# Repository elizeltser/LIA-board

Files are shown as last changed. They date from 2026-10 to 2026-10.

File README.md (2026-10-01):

# GMOS LIA Readout Board
 
KiCad project implementing the PCB for the GMOS readout based on the lock-in amplifier (LIA) approach. The board replaces the bench setup (SR860 lock-in + SR560 pre-amplifier + lab supplies) used for the 3T differential measurement of the GMOS active/blind transistor pair.
 
> **Legend:** `TODO` marks design work still to be done. `ASSUMPTION` marks a value used for sizing that must be confirmed.
 
---
 
## Table of Contents
 
1. [Schematic Overview](#1-schematic-overview)
2. [Measurement Principle & Design Considerations](#2-measurement-principle--design-considerations)
3. [DC (Power) Section](#3-dc-power-section)
4. [Analog Section](#4-analog-section)
5. [Digital Section](#5-digital-section)
6. [Power Budget](#6-power-budget)
7. [Simulation](#7-simulation)
8. [Lab Tests](#8-lab-tests)
9. [Open Items](#9-open-items)
10. [References](#10-references)
---
 
## 1. Schematic Overview
 
The schematic is split into the following sheets:
 
| Sheet | Content |
|---|---|
| 1 | Connectors, GMOS socket |
| 2 | Analog readout section |
| 3 | Digital readout section |
| 4 | DC (power) section |
 
---
 
## 2. Measurement Principle & Design Considerations
 
### 2.1 Device and Sensing Mechanism
 
The GMOS is a micromachined CMOS-SOI pixel containing a transistor (29 nMOS devices in parallel, W = 204 µm, L = 4.15 µm) and an integrated heating resistor. Each package provides two usable differential channels, each composed of an **active** pixel (exposed, with catalytic layer) and a **blind** pixel (inert reference).
 
Gas combustion on the catalytic layer releases heat, raising the active pixel temperature by ΔT. This shifts the threshold voltage and subthreshold drain current of the active transistor relative to the blind one, and the difference appears as a differential signal between the two drain nodes. Because the blind pixel sees the same heater, ambient and supply conditions, common-mode drifts are rejected by the differential readout.
 
### 2.2 3T Readout Method
 
Each transistor is operated in a three-terminal configuration:
 
- **Gate:** DC bias plus a small sine excitation at the lock-in reference frequency.
- **Drain:** connected through a series load resistor R_D (≈ 330 kΩ) to a programmable supply.
- **Heater:** DC voltage, trimmed per pixel to equalize the drain currents of the active/blind pair.
The gate modulation δV_GS produces a drain-current modulation g_m·δV_GS, which R_D converts to a voltage. The lock-in output is therefore proportional to the differential transconductance:
 
$$
\Delta v_{d} = -(g_{m,A} - g_{m,B})\cdot \delta V_{GS}\cdot R_D
$$
 
The minus sign reflects the inverting common-source stage. The phase θ carries information on reactive elements in the signal path and is used for calibration.
 
### 2.3 Bench Setup → Board Block Mapping
 
| Bench instrument / setting | Board block | Notes |
|---|---|---|
| SR860 reference out, 990 mV offset | Gate DC DAC + scaling op-amp + summing amp | Board range 0.97–1.2 V |
| SR860 reference out, 5 mVrms (≈ 14.1 mVpp) | Quadrature oscillator (518 Hz) + attenuating summing amp | Board: 5 mVpp |
| Lab supply on drain resistors | Drain DACs + scaling op-amps + R_D | Board range 2.7–3.5 V |
| Lab supply on heaters (2.7–2.9 V) | Heater DACs + driver op-amps | Board range 2.5–4.0 V |
| SR560: differential input, gain 20 V/V, BPF 300 Hz–1 kHz (6 dB/oct) | INA (G = 10, DC-coupled) → SK HPF → SK LPF → ×4 | Board: 40 V/V, 377–711 Hz (12 dB/oct) |
| SR860 demodulator (X, Y, R, θ) | AD630 pair + post-LPF (τ = 500 ms) + 24-bit ADC; R, θ computed in MCU/PC | |
 
As on the bench (SR560 differential input stage, then filters), the differential conversion happens first and the filtering is done once on the difference signal.
 
### 2.4 Transistor Operating Point
 
The GMOS must operate in subthreshold (weak inversion), where the temperature coefficient of the current is maximal. Two conditions must hold simultaneously:
 
$$
V_{GS} < V_T \approx 1.33\ \mathrm{V}, \qquad V_{DS} > \frac{3 k_B T}{q}
$$
 
The second condition must be evaluated at the **pixel** temperature:
 
| Pixel temperature | 3·k_B·T/q |
|---|---|
| 300 K | 77.6 mV |
| 400 K | 103.4 mV |
| 573 K (300 °C) | 148.1 mV |
| 673 K (400 °C) | 174.0 mV |
 
The quiescent drain voltage (source grounded) is
 
$$
V_{DS} = V_{\mathrm{supply}} - I_{DS}\,R_D
$$
 
With I_DS = 5–10 µA and R_D = 330 kΩ the drain node sits at 50–250 mV. The 50 mV lower bound is kept so that the transistors can also be characterized with the heaters off (pixel at room temperature). At elevated pixel temperature the firmware keeps V_DS above the value in the table.
 
**AC drain swing.** The 3T stage is a common-source amplifier. Assuming r_0 ≫ R_D, with g_m = I_DS/(n·k_B·T/q):
 
$$
v_{d,pp} \approx g_m R_D\cdot \delta V_{GS,pp} = \frac{I_{DS} R_D}{n\cdot k_B T/q}\cdot \delta V_{GS,pp}
$$
 
| Pixel temperature | I_DS·R_D = 1.65 V (5 µA) | I_DS·R_D = 3.3 V (10 µA) |
|---|---|---|
| 300 K | gain ≈ 40 → ≈ 200 mVpp | gain ≈ 80 → ≈ 400 mVpp |
| 673 K | gain ≈ 18 → ≈ 90 mVpp | gain ≈ 36 → ≈ 180 mVpp |
 
> (n = 1.6, δV_GS = 5 mVpp.) 
 
This is an upper bound. A finite r_0 lowers it. The bench data ([§2.5](#25-expected-signal-level-from-bench-data)) suggests the real stage gain is lower than this estimate. For clean small-signal operation the swing must also respect the V_DS limit:
 
$$
V_{DS,\mathrm{DC}} - \frac{v_{d,pp}}{2} > \frac{3 k_B T}{q}
$$
 
The drains carry this signal as **common mode** (both transistors share the gate excitation), which the readout must reject ([§2.7](#27-common-mode-rejection)).
 
The gate excitation must remain a small signal relative to n·k_B·T/q ≈ 41 mV (300 K) to 93 mV (673 K); 5 mVpp satisfies this.
 
### 2.5 Expected Signal Level (from Bench Data)
 
The SR860 reports X, Y and R as rms values of the input component at the reference frequency. Bench measurements gave at most 400 mV on X/Y with the SR560 at 20 V/V and a 5 mVrms excitation, so:
 
| Quantity | Bench (5 mVrms ≈ 14.1 mVpp excitation) | Board (5 mVpp excitation) |
|---|---|---|
| Differential drain signal, rms | 400 mV / 20 = 20 mVrms | 7.1 mVrms |
| Differential drain signal, peak | 28.3 mV | 10.0 mV |
| Differential drain signal, peak-to-peak | 56.6 mVpp | 20.0 mVpp |
 
The board value scales by the excitation ratio (5 mVpp / 14.1 mVpp = 0.354). The bench figure is consistent with the device physics: it corresponds to a Δg_m/g_m of the order of 10–20 % of the drain swing, and the fact that the ideal r_0 ≫ R_D swing at bench excitation (0.6–1.1 Vpp) could not fit inside a 50–250 mV drain DC level indicates a lower real stage gain. The chain gain ([§2.9](#29-gain-distribution-headroom-and-demodulator-output)) is set from the **board** column with 2× headroom.
 
- [ ] TODO: Confirm on the bench: drain AC swing per drain (oscilloscope) and maximum X/Y at the planned operating points ([LAB-1](#lab-1-drain-node-waveforms-oscilloscope), [LAB-2](#lab-2-bench-lock-in-reference-levels-sr560--sr860)).
### 2.6 Front End: Differential Conversion First
 
The two drains (of the channel selected by the DPDT switch) go directly to a DC-coupled instrumentation amplifier (INA828, G = 10), followed by a single band-pass (Sallen-Key HPF + Sallen-Key LPF) and a ×4 gain stage.
 
**Drain loading.** The transistor behaves as an AC current source g_m·δV_GS feeding the drain node, and everything attached to the node is in parallel for that current:
 
$$
v_d = g_m\cdot \delta V_{GS}\cdot \left(R_D \parallel r_0 \parallel Z_{\mathrm{in}}\right)
$$
 
A Sallen-Key filter connected directly to the drain would present Z_in of a few kΩ to tens of kΩ and attenuate the signal by tens of times. The INA828 inputs are high-impedance (GΩ-level resistance, pA-to-sub-nA bias current, a few pF; verify against the datasheet), so Z_in ≫ R_D and the loading problem disappears without dedicated buffers. What remains is the drain-node capacitance (INA input + switch + traces, assumed ≈ 20 pF), which forms a pole with R_D:
 
$$
f_p = \frac{1}{2\pi R_D C_{\mathrm{node}}} \approx 24\ \mathrm{kHz}
$$
 
far above 518 Hz; only its mismatch between the two drains matters ([§2.7](#27-common-mode-rejection)). The input bias current flows through R_D and shifts each drain DC level by I_B·R_D (≤ ≈ 0.3 mV for 1 nA), which is calibrated by the drain-voltage measurement.
 
**DC headroom.** The INA is DC-coupled, so it amplifies the DC mismatch between the drains: ±200 mV mismatch → ±2 V at the INA output, inside its swing on ±5 V. The HPF removes it before the ×4 stage. Requirement: drain DC mismatch ≤ ±200 mV (set by the heater/drain trim).
 
**Noise.** R_D sets the dominant white-noise floor:
 
$$
e_{n,R_D} = \sqrt{4 k_B T R_D} \approx 74\ \mathrm{nV/\sqrt{Hz}}, \qquad \sqrt{2}\,e_{n,R_D} \approx 105\ \mathrm{nV/\sqrt{Hz}}\ \text{(differential)}
$$
 
The INA828 at G = 10 contributes ≈ 11 nV/√Hz input-referred (7 nV/√Hz input stage, 90 nV/√Hz output stage ÷ 10; datasheet typical values). Filter and gain-stage noise is divided by 10 when referred to the input and is negligible.
 
**1/f noise and reference frequency.** The transistor 1/f corner is ≈ 200 Hz at typical I_DS, below the band-pass −3 dB edge (377 Hz). 518 Hz lies between the 10th (500 Hz) and 11th (550 Hz) mains harmonics and well above the pixel thermal bandwidth (≈ 16 Hz).
 
**DC leakage on the drain nodes.** Any DC current drawn from the node produces an offset (1 nA → 330 µV). Use guard rings and keep-outs around the drain traces, and the low-leakage switch (AN-29c).
 
**Load resistor quality.** R_D sets both the signal gain and the CMRR ([§2.7](#27-common-mode-rejection)). Use 0.1 %, ≤ 25 ppm/°C thin-film resistors, placed together so the active and blind resistors track thermally.
 
### 2.7 Common-Mode Rejection
 
With the INA first, the CM-to-DM conversion comes from mismatch between the two drain nodes (R_D and node capacitance), not from the filters. Monte-Carlo, 50 000 trials (Python; 60-run cross-check in SPICE, [§7](#7-simulation)):
 
| R_D tolerance | C_node (20 pF) mismatch | INA CMRR | System CMRR median | 99 % worst |
|---|---|---|---|---|
| 0.05 % | ±5 % | 90 dB | 62 dB | 54 dB |
| **0.1 %** | **±10 %** | **90 dB** | **56 dB** | **48 dB** |
| 0.1 % | ±20 % | 90 dB | 52 dB | 42 dB |
| 1 % | ±10 % | 90 dB | 44 dB | 35 dB |
| 0.1 % | ±10 % | 80 dB | 56 dB | 48 dB |
 
A realistic system CMRR is therefore ≈ 50–60 dB, limited by R_D matching and by keeping the two drain-node layouts symmetric (equal trace lengths, same switch channel type). The INA's own CMRR (80–90 dB+) does not limit it. At 56 dB, a 300 mVpp common-mode drain swing leaks as ≈ 0.5 mVpp apparent differential signal, ≈ 2.5 % of the expected 20 mVpp board signal; the capacitive part appears mostly in quadrature (Y).
 
### 2.8 Band-Pass Filter Design
 
The band-pass is a 2nd-order unity-gain Sallen-Key high-pass followed by a 2nd-order unity-gain Sallen-Key low-pass, both tuned to f_0 = 518 Hz with Q = 1. At f_0 the high-pass contributes +90° and the low-pass −90°, so the filter has **unity gain and 0° phase at the reference frequency**, with 40 dB/decade slopes on each side.
 
$$
H(s) = \frac{(s/\omega_0)^2}{(s/\omega_0)^2 + \frac{s}{Q\omega_0} + 1}\cdot\frac{1}{(s/\omega_0)^2 + \frac{s}{Q\omega_0} + 1}, \qquad \omega_0 = 2\pi\cdot 518\ \mathrm{Hz}
$$
 
Trade-off between section Q, bandwidth and sensitivity to oscillator drift (±1 %):
 
| Section Q | Gain at f_0 | −3 dB band | Rel. attenuation 50 Hz / 150 Hz / 1036 Hz (2f) / 1554 Hz (3f) | Phase change over ±1 % frequency |
|---|---|---|---|---|
| 0.707 (HP 400 Hz, LP 670 Hz) | 0.74 | 318–843 Hz | −34 / −15 / −6 / −12 dB | 2.9° |
| **1 (selected)** | **1.00** | **377–711 Hz** | **−41 / −21 / −10 / −18 dB** | **4.6°** |
| 1.5 | 2.25 | 419–641 Hz | −48 / −27 / −16 / −25 dB | 6.9° |
| 2 | 4.0 | 441–608 Hz | −53 / −32 / −20 / −29 dB | 9.2° |
 
Q = 1 is selected because higher Q increases the phase sensitivity to oscillator drift (θ moves with frequency) while the extra attenuation is modest. R is insensitive to the ±1 % drift (< 0.01 dB).
 
Component relations for unity-gain Sallen-Key sections (derived symbolically; ratio 4Q² = 4 for Q = 1):
 
| Section | Components | Relations | Values |
|---|---|---|---|
| HPF | C1 = C2 = C (series), R_f (cap junction → output), R_g (+input → ground) | Q = ½·√(R_g/R_f), R_f = 1/(2·Q·ω_0·C), R_g = 4Q²·R_f | C = 33 nF, R_f = 4.64 kΩ, R_g = 18.56 kΩ (4 × 4.64 kΩ in series) |
| LPF | R1 = R2 = R (series), C1 (junction → output), C2 (+input → ground) | Q = ½·√(C1/C2), C2 = 1/(2·Q·ω_0·R), C1 = 4Q²·C2 | R = 4.64 kΩ, C2 = 33 nF, C1 = 132 nF (4 × 33 nF in parallel) |
 
Building the 4:1 ratios from identical parts keeps the ratio tracking over temperature and tolerance. Use C0G/NP0 1 % capacitors and 0.1 % thin-film resistors. Tolerance spread at f_0 (Monte-Carlo):
 
| Components | Gain σ | Gain 99 % range | Phase σ | Phase 99 % range |
|---|---|---|---|---|
| R 0.1 %, C 1 % (C0G) | 0.06 dB | ±0.14 dB | 0.66° | ±1.6° |
| R 1 %, C 5 % | 0.31 dB | ±0.72 dB | 3.4° | ±8.2° |
 
The board-to-board phase offset is removed by the phase calibration ([§2.13](#213-calibration-considerations)).
 
### 2.9 Gain Distribution, Headroom and Demodulator Output
 
The AD630 runs on the ±5 V analog rails, its minimum supply. At ±5 V its datasheet ranges are [[D4]](#ref-d4):
 
- **Signal inputs:** (−V_S + 4) to (+V_S − 1) = **−1 V to +4 V**. The usable symmetric swing is therefore ±1 V; the design limit is ±0.8 V peak.
- **Comparator inputs:** (−V_S + 3) to (+V_S − 1.5) = **−2 V to +3.5 V**. The sin/cos references (≈ 6.3 Vpp from the oscillator, [§4.5](#45-quadrature-oscillator-design)) are attenuated to ≈ 2 Vpp (±1 V) by a 21.5 kΩ / 10 kΩ divider before the comparator inputs. With a ±1.5 mV switching window, a 1 V-peak reference gives a zero-crossing error of ≈ 0.5 µs (≈ 0.09°).
Gain distribution:
 
| Stage | Gain | Expected max (board, [§2.5](#25-expected-signal-level-from-bench-data)) | Linear limit |
|---|---|---|---|
| Drain differential | — | 10 mV peak | 20 mV peak (40 mVpp) |
| INA828 (G = 10, R_G = 5.56 kΩ) | 10 | 0.1 V peak (+ DC mismatch × 10) | |
| SK HPF + SK LPF | 1 at f_0 | 0.1 V peak | |
| Non-inverting gain stage | 4 | 0.4 V peak | 0.8 V peak |
| AD630 (gain 1, lock-in) | 1 | DC: 0.25 V | DC: 0.51 V |
| Post-LPF + level shift | 3 | ±0.76 V around 2.5 V | ±1.53 V around 2.5 V |
| ADS1220 (±2.048 V full scale) | — | 37 % FS | 75 % FS |
 
The expected maximum sits at half the AD630 linear range, leaving 2× headroom for larger differentials. If the excitation is later raised to the bench level (≈ 14 mVpp), the ×4 stage gain should be reduced to ≈ ×1.5 (resistor change).
 
The AD630 in full-wave (square-wave reference) operation produces a DC output, and the complete chain scale factor at the ADC input is:
 
$$
V_X = \frac{2}{\pi}\,G\,\hat{v}_{\mathrm{diff}}\cos\theta, \qquad V_Y = \frac{2}{\pi}\,G\,\hat{v}_{\mathrm{diff}}\sin\theta, \qquad V_{X,\mathrm{ADC}} = 3\cdot\frac{2}{\pi}\cdot 40\cdot\hat{v}_{\mathrm{diff}}\cos\theta \approx 76.4\,\hat{v}_{\mathrm{diff}}\cos\theta
$$
 
(G = 40 to the AD630 input.) To compare with SR860 readings (rms), use v̂_diff = √2·v_rms.
 
### 2.10 Demodulator Low-Pass Filter and Oversampling
 
The post-AD630 low-pass filter is τ = 500 ms (first order, f_c = 1/(2πτ) = 0.318 Hz, equivalent noise bandwidth 1/(4τ) = 0.5 Hz). It attenuates the 2f (1036 Hz) ripple of the demodulator output by ≈ 70 dB, and the ADS1220 digital filter adds further rejection.
 
Oversampling can only **lengthen** the effective time constant (narrow the bandwidth further, lower noise) by digital averaging. It cannot make the response faster than the analog τ, because content above 0.318 Hz is already removed before the ADC. The analog τ is therefore fixed at 500 ms (the shortest response needed); any longer effective time constant is implemented in software by averaging. The ADS1220 provides 20–1000 SPS (2000 SPS turbo), so even multiplexing X and Y gives ≥ 10 samples per τ.
 
Settling after a step (channel switch, operating-point change): 3.5 s to 0.1 % (6.9τ), 6.9 s to 1 ppm (13.8τ).
 
### 2.11 Oscillator Stability
 
Required frequency stability: ±1 % (≈ ±5 Hz). Within ±1 % the band-pass phase moves by ±2.3° (θ) and R is unaffected. The AD630 references come from the same oscillator, so the reference always tracks the excitation frequency; only the filter phase moves. The oscillator design, its frequency accuracy and its distortion are covered in [§4.5](#45-quadrature-oscillator-design).
 
### 2.12 Layout & Grounding Considerations
 
- Separate analog and digital ground regions joined at a single point near the power entry; route no digital signals over the analog front end.
- Place the buck and IBB converters at the far end of the board from the GMOS socket and front end.
- Route the two drain nodes (socket → switch → INA) symmetrically: equal lengths, same layer, guarded. Their capacitance mismatch sets the quadrature part of the CMRR ([§2.7](#27-common-mode-rejection)).
- Keep the oscillator (≈ 6.3 Vpp) away from the drain nodes; the ≈ 1260:1 attenuated gate path must keep oscillator pick-up into the drains far below the signal.
- Isolate the USB link from the analog ground ([§5.3](#53-pc-link)) to avoid a ground loop through the PC that injects mains harmonics.
- Keep R_D, the band-pass components and the precision references away from heat sources (heaters, LDOs).
### 2.13 Calibration Considerations
 
- The filters, INA and AD630 introduce a residual phase shift at 518 Hz (≈ ±1.6° board-to-board, [§2.8](#28-band-pass-filter-design)); record it with a known test signal and subtract it from θ.
- The sign convention follows the inverting common-source stage: with the sin reference, g_m,A > g_m,B gives negative X.
- The CM-to-DM leakage ([§2.7](#27-common-mode-rejection)) can be measured with matched operating points and subtracted, keeping in mind it scales with g_m.
- The drain current is calculated from the measured drain-node voltage and the known drain supply; R_D values should be measured in-circuit once and stored.
---
 
## 3. DC (Power) Section
 
### 3.1 Purpose
 
To keep the board portable and minimize the number of external supply ports, all required voltage rails are generated on-board from a single input.
 
### 3.2 Architecture
 
`VIN` feeds two parallel chains:
 
- **Positive chain:** a buck converter generates an intermediate rail (~7 V), which feeds two linear regulators in parallel (+5 V analog, +3.3 V digital).
- **Negative chain:** a buck converter in inverting buck-boost (IBB) topology, per TI SNVA866B [[A1]](#ref-a1), generates an intermediate rail (~−7 V), which feeds one negative linear regulator (−5 V analog).
```mermaid
flowchart LR
    VIN["VIN 11–15 V<br/>TVS"] --> BUCK["LMR51430XF buck<br/>V_positive"]
    VIN --> IBB["LMR51430XF IBB<br/>V_negative"]
    BUCK --> LDO5["ADP7118-5.0<br/>5V_analog"]
    BUCK --> LDO33["ADP7118-3.3<br/>3V3_digital"]
    IBB --> LDON5["LT3094<br/>N5V_analog"]
```
 
### 3.3 Requirements
 
| ID | Parameter | Value |
|----|---|---|
| DC-1 | Input voltage range | 11–15 V |
| DC-2 | Intermediate rails (buck / IBB) | ≈ +7 V / ≈ −7 V (reduces LDO dissipation) |
| DC-3 | Max ripple on intermediate rails | 10 % of rail voltage (design achieves < 0.2 %) |
| DC-4 | Analog rails | +5 V, −5 V (linear regulated) |
| DC-4a | Rail-reversal protection | Schottky diodes from +5 V to GND and from GND to −5 V, preventing either rail being pulled past ground during power sequencing ([§3.5.4](#354-protection-and-sequencing)) |
| DC-5 | Digital rail | +3.3 V (linear regulated) |
| DC-6 | Load current per rail | See [Power Budget](#6-power-budget): +5 V ≥ 114 mA, −5 V ≥ 56 mA, +3.3 V ≥ 74 mA, +7 V ≥ 188 mA, −7 V ≥ 56 mA (with margin) |
| DC-7 | Converter switching mode | Forced PWM (fixed frequency) at all loads, so no light-load burst frequencies fall in the 377–711 Hz signal band |
 
### 3.4 Component Selection
 
| Function | Part | Key specs | Why | Stock / price (Mouser, 2026-10-01) |
|---|---|---|-----|---|
| +7 V buck | LMR51430XFDDCR | 4.5–36 V in, 3 A, 500 kHz **FPWM**, V_FB = 0.6 V, internally compensated, 70 ns min on-time, SOT-23-6 | Wide V_IN covers the IBB stress (22 V); FPWM avoids PFM bursts near the signal band; one part type for both converters | 1918 / USD 1.84 |
| −7 V IBB | LMR51430XFDDCR | Same part, IC ground tied to −7 V | BOM reuse | (same) |
| +5 V analog LDO | ADP7118ARDZ-5.0-R7 | 20 V in, 200 mA, 11 µVrms, PSRR 88 dB @ 10 kHz / 68 dB @ 100 kHz / 50 dB @ 1 MHz, 200 mV dropout | Low noise, adequate PSRR with π pre-filter, 60 % loaded at worst case | 64 / USD 2.83 (low stock; alt. LT3045EMSE, 1188 in stock) |
| +3.3 V digital LDO | ADP7118ARDZ-3.3-R7 | As above | Same family as +5 V | 625 / USD 2.83 (cheaper alt. TLV76733, 16 V/1 A) |
| −5 V analog LDO | LT3094EMSE | −1.8 to −20 V in, 500 mA, 0.8 µVrms, PSRR 74 dB @ 1 MHz, 235 mV dropout, V_OUT set by 100 µA × R_SET | Very high PSRR at the switching frequency | 5507 / USD 10.07 |

### 3.5 Design Calculations
 
#### 3.5.1 Positive Buck (LMR51430XF, +7 V)
 
| Item | Calculation | Value |
|---|---|---|
| Feedback divider | V_OUT = 0.6 V · (1 + R_top/R_bot), R_bot = 10.0 kΩ | R_top = 107 kΩ (1 %) → 7.02 V |
| Duty cycle | D = V_OUT/V_IN | 0.47 – 0.64 (on-time 0.93–1.28 µs ≫ 70 ns min) |
| Inductor | Ripple ratio 20–60 % of 3 A per datasheet; L = V_OUT(V_IN − V_OUT)/(V_IN·f_SW·ΔI_L) | **L = 8.2 µH** → ΔI_L = 0.62 A @ 11 V (21 %), 0.91 A @ 15 V (30 %) |
| Inductor peak current (normal) | I_OUT + ΔI_L/2 = 0.188 + 0.46 | ≈ 0.65 A → I_sat ≥ 1.5 A |
| Output ripple | ΔV = ΔI_L/(8·f_SW·C_OUT), C_OUT,eff ≈ 20 µF (2 × 22 µF 25 V X7R 1210) | 7.8–11.4 mV (≈ 0.16 %) |
| Input capacitors | | 2 × 4.7 µF 50 V X7R + 100 nF |
| Bootstrap | | 100 nF (CB pin) |
 
> EN is tied directly to VIN, which the datasheet allows (EN ≤ V_IN + 0.3 V) [[D1]](#ref-d1). The converter therefore starts at its internal UVLO; no external UVLO divider is fitted.
 
> In a short circuit fault the inductor current reaches the high-side current limit (up to 6.68 A) before hiccup mode engages. Choosing I_sat above that limit is the robust option.
 
#### 3.5.2 Inverting Buck-Boost (LMR51430XF, −7 V)
 
The IC ground pin connects to −V_OUT. In this case the IC sees V_IN + |V_OUT| = 18–22 V which is lower that the allowed 36V limit.
 
| Item | Calculation | Value |
|---|---|---|
| Feedback divider | Same ratio, referenced to IC ground (−V_OUT): R_top from system GND to FB, R_bot from FB to −V_OUT | 107 kΩ / 10.0 kΩ → −7.02 V |
| Duty cycle | D = \|V_OUT\|/(V_IN + \|V_OUT\|) | 0.32 – 0.39 |
| Average inductor current | I_L = I_OUT/(1 − D), design I_OUT = 150 mA | 0.22 – 0.25 A |
| Inductor | L = 8.2 µH (same part as buck); ΔI_L = V_IN·D/(L·f_SW) | 1.04 – 1.16 A |
| Peak inductor current | I_L + ΔI_L/2 | ≈ 0.80 A |
| Max available output current | (I_LIM,min − ΔI_L/2)·(1 − D) | ≈ 1.9 A ≫ 0.15 A |
| Output ripple | ΔV ≈ I_OUT·D/(f_SW·C_OUT), C_OUT,eff ≈ 20 µF | ≈ 5–6 mV (+ ESR × I_peak) |
| Right-half-plane zero | f_RHPZ = (1 − D)²·R_LOAD/(2π·D·L) at 150 mA | 0.87 – 1.3 MHz ≫ loop crossover |
| Capacitors | C_IN between VIN and −V_OUT (rated ≥ 50 V) plus VIN to GND; C_OUT between GND and −V_OUT | 2 × 4.7 µF 50 V; 2 × 22 µF 25 V |
 
> EN is tied directly to the system VIN. EN is referenced to the IC ground (−V_OUT), so it sees V_IN + |V_OUT| ≤ 22 V, the same as the IC's VIN pin, which is within the EN ≤ V_IN + 0.3 V rating [[D1]](#ref-d1).
 
#### 3.5.3 Linear Regulators
 
| Regulator | Settings | Dissipation (worst case) |
|---|---|---|
| ADP7118-5.0 (+5 V) | Fixed output; C_IN, C_OUT ≥ datasheet minimum (use 4.7 µF X7R) | (7.02 − 5) V × 114 mA ≈ 0.23 W |
| ADP7118-3.3 (+3.3 V) | Fixed output; as above | (7.02 − 3.3) V × 74 mA ≈ 0.28 W |
| LT3094 (−5 V) | R_SET = 5 V / 100 µA = 49.9 kΩ 0.1 % (→ −4.99 V); C_SET 4.7 µF; C_OUT 10 µF ceramic; C_IN 10 µF | 2 V × 56 mA ≈ 0.11 W |
 
> No π filter is populated between the switching rails and the LDOs. Each path has a series 0 Ω resistor with two DNP placeholders (π-filter footprint), so a ferrite bead and capacitors can be fitted later if 500 kHz ripple shows up downstream. The ADP7118 PSRR falls to ≈ 50–60 dB at that frequency [[D2]](#ref-d2).
 
#### 3.5.4 Protection and Sequencing
 
- Input: TVS (16 V stand-off). We assume the board is powered by a regular lab-bench power supply programmed with internal current limit so PTC/Fuse is not needed.
- Split rails: Schottky clamps from +5 V to GND and from GND to −5 V prevent either rail being pulled past ground during start-up.
---
 
## 4. Analog Section
 
### 4.1 Functions
 
The analog section is responsible for:
 
1. Gate bias: DC component (DAC) summed with the AC excitation sine.
2. Drain bias: DAC-controlled voltage applied through a series resistor, with drain-voltage (current) measurement.
3. Heater bias: DAC-controlled DC voltage, with current measurement.
4. Differential amplification and band-pass filtering of the active − blind drain signal.
5. Demodulation into in-phase (X) and quadrature (Y) components using AD630s.
6. Digitization of X, Y and the bias currents.
7. Channel selection between the two differential channels of the GMOS package.
### 4.2 Signal Chain Overview
 
```mermaid
flowchart LR
    OSC["Quadrature oscillator<br/>≈ 521 Hz, ≈ 6.3 Vpp"] -->|sin| SUM["Summing amp<br/>÷ ≈ 1260"]
    GDAC["Gate DC DAC"] --> SUM
    SUM --> GATE["GMOS gates"]
    DDAC["Drain DACs (4 ch) + R_D"] --> DRAIN["GMOS drains"]
    HDAC["Heater DACs (4 ch) + drivers"] --> HEAT["GMOS heaters"]
    DRAIN --> SW["Channel switch<br/>(DPDT)"]
    SW --> INA["INA828<br/>G = 10, DC-coupled"]
    SW --> DCS["Drain DC sense<br/>→ MCU ADC"]
    INA --> HPF["SK HPF<br/>518 Hz, Q = 1"]
    HPF --> LPF["SK LPF<br/>518 Hz, Q = 1"]
    LPF --> G4["Gain ×4"]
    G4 --> AD630X["AD630 — X"]
    G4 --> AD630Y["AD630 — Y"]
    OSC -->|"sin reference"| AD630X
    OSC -->|"cos reference"| AD630Y
    AD630X --> XPLPF["X channel LPF"]
    AD630Y --> YPLPF["Y channel LPF"]
    XPLPF --> ADC["ADS1220"]
    YPLPF --> ADC["ADS1220"]
```
 
### 4.3 Requirements
 
#### 4.3.1 Excitation (Gate)
 
| ID | Parameter | Value |
|----|---|---|
| AN-1 | Excitation frequency | 518 Hz, generated by an op-amp quadrature oscillator |
| AN-2 | Oscillator outputs | sin → gate summing amp and AD630 (X) reference; cos → AD630 (Y) reference |
| AN-3 | Gate voltage | Summing op-amp output: sine + DC from gate DAC |
| AN-4 | Gate AC amplitude | 5 mVpp, centered on the gate DC level set by the gate DAC (AN-5) | 
| AN-5 | Gate DC range / resolution | 970 mV – 1.2 V, 100 µV resolution. One 16-bit DAC channel scaled/offset by a precision op-amp stage (≈ 3.8 µV LSB); DAC + op-amp offset, drift and noise must hold the 100 µV resolution |
| AN-6 | Oscillator output amplitude | ≤ 10 Vpp, zero-centered; design value ≈ 6.3 Vpp set by a soft zener limiter ([§4.5](#45-quadrature-oscillator-design)). The gate summing amp attenuates it to AN-4 (≈ 1260×). The AD630 comparator inputs receive it through a 21.5 kΩ / 10 kΩ divider (≈ ±1 V; comparator range −2 V to +3.5 V at ±5 V supply) |
| AN-7 | Oscillator frequency stability | ±1 % (≈ ±5 Hz); C0G 1 % capacitors and 0.1 %, ≤ 25 ppm/°C resistors in the frequency-setting network ([§4.5](#45-quadrature-oscillator-design)) |
| AN-7a | Oscillator frequency monitoring | The divided sin reference also feeds an STM32G474 internal comparator → timer input capture, so firmware measures and logs the actual excitation frequency |
| AN-7b | Oscillator distortion | THD ≤ ≈ 1 % (simulated 0.5–0.8 %, [§4.5](#45-quadrature-oscillator-design)); verify on hardware |
 
#### 4.3.2 Drain Bias
 
| ID | Parameter | Value |
|----|---|---|
| AN-8 | Topology | DAC + amplifier, connected to the drain through a series current-limiting resistor (330 kΩ, 0.1 %, ≤ 25 ppm/°C) |
| AN-9 | Voltage range | 2.7–3.5 V |
| AN-10 | Voltage resolution / accuracy | Relaxed from 10 µV to ≈ 15 µV resolution: 16-bit DAC channel, 2.5 V span compressed ×0.4 to 2.6–3.6 V. Absolute accuracy is set by the DAC's internal reference (≈ mV level); it is not critical because the drain current is measured back (AN-11). 15 µV corresponds to a 46 pA drain-current step (≈ 5 ppm of 10 µA) |
| AN-11 | Current measurement | Each drain of the selected channel: high-Z buffer → RC LPF (≈ 1 Hz) → gain 8 → 12-bit MCU ADC (2.5 V ref). ≈ 76 µV/LSB at the drain → ≈ 0.23 nA/LSB; current = (V_supply − V_D)/R_D |
| AN-12 | Drain outputs | 4 independent DAC channels (one per pixel), no switching of bias lines; at most 2 active at a time (the selected channel). Unused outputs set to 0 V by firmware |
| AN-12a | Drain operating point | Drain current 5–10 µA → drain node 50–250 mV DC. 50 mV lower bound allows characterization with heaters off; with heaters on, firmware keeps V_DS above 3·k_B·T/q at pixel temperature plus half the AC swing ([§2.4](#24-transistor-operating-point)) |
| AN-12b | Drain DC mismatch (active − blind) | ≤ ±200 mV (INA DC headroom, [§2.6](#26-front-end-differential-conversion-first)) |
 
#### 4.3.3 Heaters
 
| ID | Parameter | Value |
|----|---|---|
| AN-13 | Topology | DAC + op-amp driver, DC voltage; feedback taken at the heater terminal (Kelvin) so the shunt drop is inside the loop |
| AN-14 | Voltage range | 2.5–4.0 V |
| AN-15 | DAC resolution | ≥ 12 bit |
| AN-16 | Heater resistance | 600 Ω – 1.2 kΩ → 2.1–6.7 mA |
| AN-17 | Heater outputs | 4 independent DAC channels (one per pixel), no switching; at most 2 active at a time |
| AN-18 | Current measurement accuracy | ≤ 100 µA. INA190A1 (G = 25) with 15 Ω shunt → 2.5 V at 6.7 mA, ≈ 1.6 µA/LSB at 12 bit; shunt drop ≤ 100 mV |
 
#### 4.3.4 Amplification & Filtering
 
| ID | Parameter | Value |
|----|---|---|
| AN-19 | Topology | Instrumentation amplifier (DC-coupled, high-Z inputs) → 2nd-order Sallen-Key HPF → 2nd-order Sallen-Key LPF → non-inverting gain stage → AD630 |
| AN-20 | Gain at 518 Hz | 40 V/V total: INA 10 × filters 1 × gain stage 4 ([§2.9](#29-gain-distribution-headroom-and-demodulator-output)) |
| AN-21 | Bandwidth | f_0 = 518 Hz, −3 dB band 377–711 Hz (section Q = 1) |
| AN-22 | Filter slopes | 40 dB/decade on each side (2 poles / 2 zeros) |
| AN-23 | Noise / CMRR | Input-referred noise ≈ 11 nV/√Hz (< 20 nV/√Hz target). INA CMRR ≥ 80 dB at 518 Hz; system CMRR ≈ 56 dB median with 0.1 % R_D and ±10 % drain-node capacitance mismatch ([§2.7](#27-common-mode-rejection)) |
| AN-23a | Linear input range | Differential drain signal ≤ 20 mV peak (40 mVpp), set by the AD630 ±0.8 V design limit ([§2.9](#29-gain-distribution-headroom-and-demodulator-output)) |
 
#### 4.3.5 Demodulation (Lock-in)
 
| ID | Parameter | Value |
|----|---|---|
| AN-24 | Demodulator | AD630 pair (X and Y) in lock-in topology, ±5 V supply |
| AN-25 | AD630 gain | 1 |
| AN-26 | Post-demodulation LPF | τ = 500 ms fixed (first order, f_c = 0.318 Hz); longer time constants in software ([§2.10](#210-demodulator-low-pass-filter-and-oversampling)). Followed by gain 3 and level shift to the ADC mid-scale (2.5 V) |
 
#### 4.3.6 Channel Selection
 
| ID | Parameter | Value |
|----|---|---|
| AN-27 | Channels | Each GMOS package has 2 differential (active/blind) channels |
| AN-28 | Selection | Digitally controlled analog switch used as DPDT (dual SPDT). Alternative: mechanical DPDT signal relay |
| AN-29 | Switched signals | Active and blind drain nodes of the selected channel (2 signals → DPDT). Bias lines are not switched (AN-12, AN-17) |
| AN-29a | Switched signal level | 50–250 mV DC + up to ≈ 400 mVpp at 518 Hz; must pass DC with minimal added noise and offset |
| AN-29b | Switch on-resistance | ≤ 100 Ω suggested (≈ 0.03 % of the 330 kΩ source) |
| AN-29c | Switch leakage | ≤ 100 pA suggested (≤ 33 µV DC error at the drain node) |
| AN-29d | Other switch parameters | Signal range inside ±5 V rails, 3.3 V logic-compatible control, break-before-make, matched channel capacitance. For a relay: low thermal EMF contacts |
 
#### 4.3.7 Data Converters
 
| ID | Parameter | Value |
|----|---|---|
| AN-30 | X/Y ADC | 24-bit ΔΣ, 2 differential inputs, SPI, 20–1000 SPS, ±2.048 V full scale around 2.5 V |
| AN-31 | Heater current ADC | 12-bit (MCU internal), must meet AN-18 for all heaters |
| AN-32 | Drain current ADC | 12-bit (MCU internal) with scaling amplifier, must meet AN-11 |
 
#### 4.3.8 Miscellaneous
 
| ID | Parameter | Value |
|----|---|---|
| AN-33 | ESD protection | Powered from +5 V, ≈ 5 mA |
 
### 4.4 Analog Component Selection (Preliminary)
 
Supply currents are datasheet maximum values where known, otherwise conservatively rounded up; verify each against the final datasheet revision. A single op-amp type (OPA2192) is used for all general-purpose positions: rail-to-rail output (needed for 4 V heater drive from +5 V), CMOS input with pA-level bias current (needed on the 330 kΩ drain nodes), ±25 µV max offset, 5.5 nV/√Hz noise. Stock checked at Mouser on 2026-10-01; parts listed with 0 stock there need a second distributor or an alternate package before ordering.
 
| Block | Function | Part | Qty | Key specs | Supply | I per unit (budget) | Notes |
|---|---|---|-----|---|---|---|---|
| Gate | Quadrature oscillator | OPA2192 | 1 (2 ch) | RRO | ±5 V | 2.4 mA | SLYT164 Fig. 8 topology with soft zener limiter; 15 nF C0G, 20.5 kΩ ([§4.5](#45-quadrature-oscillator-design)) |
| Gate | DC scaling + summing amp | OPA2192 | 1 (2 ch) | Vos ≤ 25 µV, 0.5 µV/°C | ±5 V | 2.4 mA | Scales DAC 0–2.5 V to 0.95–1.2 V (≈ 3.8 µV LSB), adds 5 mVpp sine |
| Gate | AD630 reference dividers | Resistors | 2 | 21.5 kΩ / 10 kΩ, 0.1 % | — | — | sin/cos (≈ 6.3 Vpp) → ≈ ±1 V into comparator inputs |
| Gate / Heaters / Drains | DC DAC | DAC80508 | 2 | Octal true 16-bit, internal 2.5 V ref, SPI | +5 V | 3 mA | 9 channels used: 1 gate + 4 heaters + 4 drains (7 spare). USD 20.41 each, 743 in stock. Drain offset (2.6 V) derived from the DAC reference output, so it tracks ratiometrically |
| Drain | DAC offset/scale buffer | OPA2192 | 2 (4 ch) | | ±5 V | 2.4 mA | |
| Drain | Load resistor R_D | 330 kΩ thin film | 4 | 0.1 %, ≤ 25 ppm/°C | — | — | |
| Drain | DC sense: buffer + gain 8 | OPA2192 | 2 (4 ch) | High-Z input, ≈ 1 Hz RC LPF between stages | ±5 V | 2.4 mA | After the channel switch; clamp output to ADC rail |
| Heater | Driver | OPA2192 | 2 (4 ch) | RRO, sources ≥ 10 mA | ±5 V | 2.4 mA + load | Kelvin feedback at heater; current from +5 V |
| Heater | Current sense | INA190A1 | 4 | G = 25 V/V, CM −0.2 to 40 V | +3.3 V | 0.065 mA | 15 Ω shunt; 2279 in stock |
| Front end | Channel switch | TMUX6136 | 1 | Dual SPDT, 0.5 pA on-leakage, ±16.5 V | ±5 V | 0.1 mA | 37 in stock. Alt.: latching DPDT signal relay |
| Front end | Instrumentation amp | INA828 | 1 | 7 nV/√Hz, G = 1 + 50 kΩ/R_G | ±5 V | 0.7 mA | R_G = 5.56 kΩ 0.1 % → G = 10 |
| Front end | SK HPF + SK LPF + ×4 gain | OPA2192 | 2 (3 ch + 1 spare) | f_0 = 518 Hz, Q = 1, unity-gain sections | ±5 V | 2.4 mA | C0G 1 %, 0.1 % R ([§2.8](#28-band-pass-filter-design)) |
| Demod | Balanced demodulator | AD630 | 2 | Gain ±1 internal resistors | ±5 V | 5 mA | ≈ USD 51 each, 111 in stock |
| Demod | Post-LPF + ×3 + level shift | OPA2192 | 1 (2 ch) | τ = 500 ms | ±5 V | 2.4 mA | |
| Readout | X/Y ADC | ADS1220 | 1 | 24-bit ΔΣ, 2 differential ch, SPI, ≤ 2 kSPS | AVDD +5 V, DVDD +3.3 V | 1 mA / 0.1 mA | 4023 in stock |
| Misc | ESD protection | included in GMOS package | — | | +5 V | 5 mA (total) | Per requirement AN-33 |
 
OPA2192 total: 11 duals (22 channels, 1 spare).
 
### 4.5 Quadrature Oscillator Design
 
#### 4.5.1 Topology
 
The excitation and both lock-in references come from a two-op-amp quadrature oscillator, following Figure 8 of Mancini, *Design of op amp sine wave oscillators* (TI SLYT164) [[A2]](#ref-a2). The loop consists of three matched RC sections:
 
- **U1 — non-inverting integrator:** R1C1 forms a low-pass at the non-inverting input. R3 (−input to ground) and C3 (output to −input) set a gain of (1 + sR3C3)/(sR3C3). When R1C1 = R3C3 the stage is an ideal non-inverting integrator.
- **U2 — inverting integrator:** R2 input resistor, C2 feedback capacitor.
U1's output drives U2, and U2's output feeds back to U1's input. The two integrators give the loop
 
$$
T(s) = \underbrace{\frac{1 + sR_3C_3}{sR_3C_3\,(1 + sR_1C_1)}}_{\text{U1}}\cdot\underbrace{\left(-\frac{1}{sR_2C_2}\right)}_{\text{U2}} \;\xrightarrow{R_iC_i = RC}\; -\frac{1}{(sRC)^2}
$$
 
which equals unity magnitude with the phase needed for oscillation at
 
$$
f_0 = \frac{1}{2\pi R C}
$$
 
U2 integrates U1's output, so the two outputs are inherently 90° apart: U1 output = **sin** (gate excitation, X reference), U2 output = **cos** (Y reference). 
> This oscillator needs only two op amps but has high distortion, because the amplitude is set by the op-amp non-linearity unless an auxiliary gain-control circuit is added [[A2]](#ref-a2).
 
```mermaid
flowchart LR
    COS["cos (U2 out)"] --> R1C1["R1 / C1<br/>low-pass"]
    R1C1 --> U1["U1 non-inverting integrator<br/>R3, C3 in gain network"]
    U1 --> SIN["sin (U1 out)"]
    SIN --> U2["U2 inverting integrator<br/>R2, C2 + zener limiter"]
    U2 --> COS
    SIN --> GATE["÷ ≈ 1260 → gate summing amp"]
    SIN --> RX["÷ 3.15 → AD630 X comparator<br/>+ MCU COMP (frequency)"]
    COS --> RY["÷ 3.15 → AD630 Y comparator"]
```
 
#### 4.5.2 Component Values
 
| Component | Value | Notes |
|---|---|---|
| C1, C2, C3 | 15 nF, C0G/NP0, 1 % | Frequency-setting; C0G for ±30 ppm/°C |
| R1, R2 | 20.5 kΩ, 0.1 %, ≤ 25 ppm/°C | f_0 = 1/(2π·20.5 kΩ·15 nF) = 517.6 Hz |
| R3 | 20.0 kΩ, 0.1 % | Deliberately ≈ 2.4 % below R → loop gain slightly > 1, guaranteeing start-up |
| Limiter | Back-to-back 2.7 V zeners + 4.7 kΩ series, across C2 | Soft amplitude limit ≈ ±3.2 V |
| Op amps | OPA2192 (1 dual), ±5 V | RRO; GBW ≫ f_0, so integrator phase error is negligible |
| Reference dividers | 21.5 kΩ / 10 kΩ, 0.1 % (one per output) | ≈ 2 Vpp into the AD630 comparators ([§2.9](#29-gain-distribution-headroom-and-demodulator-output)) |
 
The R3 offset that guarantees start-up also pulls the frequency slightly up, to ≈ 521 Hz (+0.6 % from 518 Hz). This is inside the ±1 % requirement and is measured by firmware (AN-7a).
 
#### 4.5.3 Amplitude Control
 
SLYT164 relies on op-amp saturation in this topology, which on ±5 V rails would mean hard clipping at the rails, high distortion and slow saturation recovery. Instead, the slight excess loop gain (R3 < R) makes the amplitude grow from start-up until a soft limiter takes over. The limiter is a series resistor and back-to-back zener pair across C2: it adds loss only near the peaks and settles the amplitude at about ±(V_Z + V_F). This keeps both op amps well inside their output swing.
 
#### 4.5.4 Frequency Accuracy and Stability
 
- **Initial accuracy:** with 1 % C and 0.1 % R, the worst case is ≈ ±1.1 %, statistically ≈ ±0.6 %. Combined with the deliberate +0.6 % offset, use 0.5 % capacitors, or trim R1/R2 after the first build, if a tighter centre frequency is wanted.
- **Thermal drift:** C0G (±30 ppm/°C) and 25 ppm/°C resistors give ≈ 0.1 % over 20 °C, well within the ±1 % stability requirement (AN-7).
- **Monitoring:** the divided sin reference also goes to an STM32G474 internal comparator and a timer input capture, so the actual frequency is logged with every data stream (AN-7a). The lock-in itself does not depend on the exact frequency, because the references come from the same oscillator.
#### 4.5.5 Quadrature Accuracy
 
With ideal integrators the outputs are exactly 90° apart. The start-up offset (R3 ≠ R) and the limiter introduce a small error (≈ 1° in simulation). This sets the X/Y orthogonality and is removed by the phase calibration ([§2.13](#213-calibration-considerations)).
 
#### 4.5.6 Effect of Distortion on the Measurement
 
Harmonics on the gate excitation produce drain signals at 2f and 3f. These are suppressed three times:
- by the band-pass (−10 dB at 2f, −18 dB at 3f, [§2.8](#28-band-pass-filter-design));
- by the square-wave demodulator, which rejects even harmonics and weights the 3rd harmonic by 1/3;
- by the small-signal operating point itself.
With ≈ 1 % THD at the oscillator, the resulting error on X/Y is of the order of
 
$$
\varepsilon \approx \mathrm{THD}_3 \cdot |H_{\mathrm{BPF}}(3f_0)| \cdot \tfrac{1}{3} \approx 0.01 \cdot 0.13 \cdot 0.33 \approx 4\times10^{-4}
$$
 
i.e. ≈ 0.04 % of the signal, which is negligible.
 
#### 4.5.7 Simulated Performance (ideal op amps, ngspice)
 
Netlist: [`simulations/quad_osc_tran.cir`](simulations/quad_osc_tran.cir).
 
| Quantity | Value |
|---|---|
| Output amplitude (sin / cos) | 6.33 / 6.28 Vpp |
| AD630 reference after divider | 2.01 Vpp |
| Frequency | 520.7 Hz |
| THD (sin / cos, 10 harmonics) | 0.52 % / 0.85 % |
| Phase sin → cos | ≈ 90.9° |
| Amplitude settling from start-up | ≈ 0.3–0.4 s |
 
- [ ] TODO: Re-run with the OPA2192 model and the selected zener part; measure amplitude, frequency and THD on the first board.
---
 
## 5. Digital Section
 
### 5.1 Requirements
 
| ID | Requirement |
|----|---|
| DG-1 | MCU controlling all DACs and ADCs of the analog section |
| DG-2 | Digital temperature sensor: commercial off-the-shelf, readily available, with open-source drivers |
| DG-3 | Digital humidity sensor: same criteria as DG-2 |
| DG-4 | Serial connection to PC: command/response plus streamed samples ([§5.3](#53-pc-link)), galvanically isolated from the analog ground |
| DG-5 | JTAG/SWD connector for MCU programming (10-pin Cortex debug header) |
| DG-6 | MCU internal 12-bit ADC used for drain and heater current measurement (AN-31, AN-32) |
 
### 5.2 Digital Component Selection (Preliminary)
 
| Function | Part | Qty | Key specs | Supply | I per unit (budget) | Notes |
|---|---|-----|---|---|---|---|
| MCU | STM32G474RET6 | 1 | Cortex-M4 170 MHz, 5× 12-bit ADC, VREFBUF, SPI/I²C/UART | +3.3 V | 40 mA | ASSUMPTION: STM32 family (lab tooling). 0 stock at Mouser at check time |
| Temperature sensor | TMP117 | 1 | ±0.1 °C, I²C | +3.3 V | 0.02 mA | Simple register map; vendor and Zephyr drivers |
| Humidity (+ temperature) sensor | SHT40 | 1 | ±1.8 %RH, ±0.2 °C, I²C | +3.3 V | 0.5 mA | Sensirion open-source embedded driver; 4755 in stock |
| USB-UART bridge | CP2102N | 1 | USB 2.0 FS, up to 3 Mbaud | USB VBUS (isolated side) | — (bus-powered) | Virtual COM port, no driver on Win10+/Linux |
| Digital isolator | ISO7721 | 1 | 2 ch (TX/RX), reinforced | +3.3 V / USB side | 2 mA per side | Breaks the PC–analog ground loop |
| Debug | 10-pin Cortex debug header | 1 | JTAG/SWD | — | — | |
| Status LEDs | — | 2 | | +3.3 V | 2 mA | |
| DAC/ADC logic I/O | (in DACs, ADS1220) | — | | +3.3 V | 0.6 mA total | |
| Pull-ups, misc | — | — | | +3.3 V | 2 mA | |
 
### 5.3 PC Link
 
**Choice.** USB-UART bridge (CP2102N) behind a digital isolator because a 2-channel UART is easy and cheap to isolate. The isolated side of the CP2102N is powered from USB VBUS.
 
**Protocol (assumption).** ASCII command/response lines for configuration (e.g. `SET GATE 0.9900`, `SET CH 1`, `STREAM ON 100`), and fixed-length binary frames for streaming.
 
**Frame and data rate.**
 
| Field | Bytes |
|---|---|
| Sync header | 1 |
| Sequence number | 2 |
| Timestamp (µs) | 4 |
| X (24-bit) | 3 |
| Y (24-bit) | 3 |
| Drain voltages, 2 × 12-bit | 4 |
| Heater currents, 2 × 12-bit | 4 |
| Status flags | 1 |
| CRC-16 | 2 |
| **Total** | **24** |
 
| Frame rate | Data rate | UART load at 921 600 baud (8N1, 10 bits/byte) |
|---|---|---|
| 20 frames/s (≈ 10 per τ) | 480 B/s | 0.5 % |
| 100 frames/s | 2.4 kB/s | 2.6 % |
| 1000 frames/s (ADS1220 max with X/Y multiplexed) | 24 kB/s | 26 % |
 
Even the ADC's maximum rate uses about a quarter of a 921 600 baud link. Environmental data (temperature, humidity) is sent in a separate frame at ≈ 1 Hz.
 
---
 
## 6. Power Budget
 
### 6.1 Assumptions
 
Datasheet maximum supply currents, every op-amp at maximum quiescent current, heater resistance 600 Ω at 4 V (6.7 mA each), and a 1.5× design margin. The nominal case has 2 heaters active (AN-17); the worst case (all 4 heaters on) sizes the regulators.
 
### 6.2 Per-Rail Current
 
| Rail | Consumer | Current |
|---|---|---|
| +5 V | OPA2192 × 11 (22 ch × 1.2 mA) | 26.4 mA |
| +5 V | Heater load current (2 × 4 V / 600 Ω) | 13.3 mA |
| +5 V | AD630 × 2 | 10 mA |
| +5 V | INA828 | 0.7 mA |
| +5 V | TMUX6136 | 0.1 mA |
| +5 V | DAC80508 × 2 | 6 mA |
| +5 V | ADS1220 (AVDD) | 1 mA |
| +5 V | ESD protection | 5 mA |
| **+5 V** | **Total (estimate / with 1.5× margin)** | **62.5 mA / 94 mA** (4 heaters: 75.9 / 114 mA) |
| −5 V | OPA2192 × 11 | 26.4 mA |
| −5 V | AD630 × 2 | 10 mA |
| −5 V | INA828 | 0.7 mA |
| −5 V | TMUX6136 | 0.1 mA |
| **−5 V** | **Total (estimate / with 1.5× margin)** | **37.2 mA / 56 mA** |
| +3.3 V | STM32G474 | 40 mA |
| +3.3 V | ISO7721 (MCU side) | 2 mA |
| +3.3 V | SHT40, TMP117 | 0.5 mA |
| +3.3 V | INA190 × 4 | 0.3 mA |
| +3.3 V | Converter logic I/O | 0.6 mA |
| +3.3 V | LEDs, pull-ups, misc | 6 mA |
| **+3.3 V** | **Total (estimate / with 1.5× margin)** | **49.4 mA / 74 mA** |
| USB VBUS | CP2102N + ISO7721 (USB side) | ≈ 15 mA (from the PC, not from the board supply) |
 
### 6.3 Regulator Loading & Input Power
 
Worst case (4 heaters active, with margin):
 
| Item | Load | Rating | Utilization |
|---|---|---|---|
| +5 V LDO (ADP7118-5.0) | 114 mA | 200 mA | 57 % |
| +3.3 V LDO (ADP7118-3.3) | 74 mA | 200 mA | 37 % |
| −5 V LDO (LT3094) | 56 mA | 500 mA | 11 % |
| +7 V buck (LMR51430) | 188 mA | 3 A | 6 % |
| −7 V IBB (LMR51430) | 56 mA (design 150 mA) | ≈ 1.9 A available | 3 % |
| LDO dissipation total | 0.23 + 0.28 + 0.11 W | | ≈ 0.62 W |
| Input power (buck η = 85 %, IBB η = 80 %) | ≈ 2.0 W | | |
| Input current at 11 V | ≈ 0.19 A | Fuse / connector ≥ 0.5 A | |
 
---
 
## 7. Simulation
 
The netlists in [`simulations/`](simulations/) use ideal op-amps and behavioral blocks so they run anywhere; each one notes where to drop in vendor models (TI OPA2192 and INA828 PSpice models, ADI AD630 macro-model) for a device-level run. They were cross-checked in ngspice with equivalent control scripts; the reference values below are from those runs.
 
| File | Analysis | What it shows |
|---|---|---|
| `simulations/bpf_mc.cir` | AC + Monte Carlo (`.step` + `mc()`) | Band-pass gain/phase at 518 Hz, −3 dB edges, tolerance spread |
| `simulations/cmrr_mc.cir` | AC + Monte Carlo | System CMRR from R_D and drain-node capacitance mismatch |
| `simulations/chain_tran.cir` | Transient, 4 s | Full chain at a selected operating point: drain swing, X/Y after the τ = 500 ms filter |
| `simulations/quad_osc_tran.cir` | Transient, 0.8 s + `.four` | Quadrature oscillator start-up, amplitude, frequency, THD, reference divider level |
 
### 7.1 Running in LTspice
 
1. **File → Open**, set the file type to *Netlists (\*.cir, \*.net, …)*, open the `.cir` file, then **Run**. No schematic is needed; LTspice simulates the netlist directly.
2. **Results of `.meas`:** *View → SPICE Error Log*. For a stepped (Monte-Carlo) run, right-click inside the log → *Plot .step'ed .meas data*. This plots each measurement against the run index; export it with *File → Export data as text* for histograms.
3. **Nominal vs Monte-Carlo:** in `bpf_mc.cir` and `cmrr_mc.cir`, set `.param Nrun=1` and the tolerances to 0 for the nominal run; `Nrun=500` with the given tolerances for Monte-Carlo. `mc(x,tol)` draws a uniform value in x·(1 ± tol) for every step.
4. **Waveforms:** click a node in the waveform viewer, or use *Plot Settings → Add Trace* with e.g. `V(out)`, `V(xlpf)`, `V(dA)-V(dB)`.
5. **Vendor models:** download the TI/ADI model file, add `.include <file>` to the netlist, and replace the `E` element of the stage with an `X` subcircuit instance using the model's pin order.
### 7.2 Running in PSpice (e.g. the free PSpice for TI)
 
1. Draw the same circuit in the schematic editor, using `Rbreak`/`Cbreak` parts for the toleranced components and giving each a model with a deviation, e.g. `.model RTOL RES(R=1 DEV=0.1%)`, `.model CTOL CAP(C=1 DEV=1%)`.
2. *Simulation Settings → Analysis: AC Sweep*, and enable *Monte Carlo/Worst Case* with e.g. 500 runs, output variable `V(out)`.
3. In *Probe*, use *Performance Analysis* with the measurement `YatX(V(out),518)` for gain and `YatX(VP(out),518)` for phase; plot them as histograms over the runs.
4. TI's OPA2192 and INA828 models are native PSpice models and drop in directly.
### 7.3 Reference Values (ideal models)
 
| Simulation | Quantity | Python analytic | ngspice (60 runs) |
|---|---|---|---|
| Band-pass, nominal | Gain / phase at 518 Hz | 1.000 / 0° | 0.9999 / 0.76° (finite E-source gain) |
| Band-pass, nominal | −3 dB edges | 377 / 711 Hz | 379 / 713 Hz |
| Band-pass MC (0.1 % R, 1 % C) | Gain σ / phase σ | 0.06 dB / 0.66° | 0.06 dB / 0.56° |
| CMRR MC (0.1 % R_D, ±10 % C_node) | Median / worst | 56 dB / 48 dB (99 %) | 57 dB / 49 dB (min of 60) |
| Full chain, 5 % Δg_m, I_D = 7.5 µA | X / Y after 3.5 s | −0.190 V / 0 V | −0.190 V / +1.6 mV |
| Quadrature oscillator | Amplitude / frequency / THD (sin) | 517.6 Hz (ideal RC) | 6.33 Vpp / 520.7 Hz / 0.52 % |
 
### 7.4 Simulation Results (to be filled in)
 
#### Monte-Carlo
 
| Simulation | Runs | Tolerances | Gain at 518 Hz (mean / σ / min–max) | Phase at 518 Hz (mean / σ / min–max) | CMRR (median / min) | Notes |
|---|---|---|---|---|---|---|
| `bpf_mc.cir` | | | | | — | |
| `cmrr_mc.cir` | | | — | — | | |
| Device-level (vendor models) | | | | | | |
 
<!-- Add plots: -->
<!-- ![Band-pass Monte-Carlo gain histogram](simulations/results/bpf_mc_gain.png) -->
<!-- ![Band-pass Monte-Carlo phase histogram](simulations/results/bpf_mc_phase.png) -->
<!-- ![CMRR distribution](simulations/results/cmrr_mc.png) -->
 
#### Quadrature Oscillator
 
| Quantity | Simulation (vendor models) | Measured (board) |
|---|---|---|
| Amplitude sin / cos (Vpp) | | |
| Frequency (Hz) | | |
| THD sin / cos (%) | | |
| Phase sin → cos (°) | | |
| Start-up time (s) | | |
 
<!-- ![Oscillator start-up and steady state](simulations/results/quad_osc_tran.png) -->
<!-- ![Oscillator spectrum](simulations/results/quad_osc_fft.png) -->
 
#### Selected Operating Point
 
| Parameter | Value |
|---|---|
| I_D (A / B) | |
| V_D (A / B) | |
| Gate DC / excitation | |
| Δg_m assumed | |
| Drain AC swing, A (Vpp) | |
| Drain differential (Vpp) | |
| AD630 input (V peak) | |
| X / Y at ADC input (V) | |
| Settling time to 0.1 % (s) | |
 
<!-- Add plots: -->
<!-- ![Band-pass Bode plot](simulations/results/bpf_bode.png) -->
<!-- ![Full chain transient: drains, AD630 input, X/Y](simulations/results/chain_tran.png) -->
 
---
 
## 8. Lab Tests
 
Results measured on the bench with lab equipment (oscilloscope, lock-in, supplies, meters) are collected here, next to the design values they verify. Raw data (scope screenshots, CSV exports, SR860 logs) go in `lab/<test-id>/`, named `YYYY-MM-DD_<short-description>.<ext>`; each results row links to its files. Add a row per run; do not overwrite earlier runs.
 
### 8.1 Equipment
 
| Instrument | Model / serial | Used in | Notes |
|---|---|---|---|
| Oscilloscope | | LAB-1, LAB-3, LAB-4 | |
| Oscilloscope probes | | LAB-1, LAB-3, LAB-4 | 10× passive (10 MΩ ∥ ≈ 10–15 pF) |
| Lock-in amplifier | SR860 [[M1]](#ref-m1) | LAB-2, LAB-5, LAB-9 | |
| Low-noise preamplifier | SR560 [[M2]](#ref-m2) | LAB-2 | |
| Function generator | | LAB-5, LAB-6 | |
| Bench power supply | | LAB-3 and board supply | Current limit set (no on-board fuse, [§3.5.4](#354-protection-and-sequencing)) |
| DMM / SMU | | LAB-7, LAB-8 | |
 
### 8.2 Test Index
 
| ID | Test | Verifies | Status |
|----|---|---|---|
| [LAB-1](#lab-1-drain-node-waveforms-oscilloscope) | Drain node waveforms (oscilloscope) | Drain DC level, AC swing, common-mode level ([§2.4](#24-transistor-operating-point)) | Not started |
| [LAB-2](#lab-2-bench-lock-in-reference-levels-sr560--sr860) | Bench lock-in reference levels | Expected signal level ([§2.5](#25-expected-signal-level-from-bench-data)) | Not started |
| [LAB-3](#lab-3-power-rails) | Power rails | DC levels, ripple ([§3.5](#35-design-calculations)) | Not started |
| [LAB-4](#lab-4-quadrature-oscillator) | Quadrature oscillator | Amplitude, frequency, THD, quadrature ([§4.5](#45-quadrature-oscillator-design)) | Not started |
| [LAB-5](#lab-5-band-pass-response) | Band-pass response | Gain/phase vs frequency ([§2.8](#28-band-pass-filter-design)) | Not started |
| [LAB-6](#lab-6-common-mode-rejection) | Common-mode rejection | System CMRR ([§2.7](#27-common-mode-rejection)) | Not started |
| [LAB-7](#lab-7-drain-bias-and-current-readback) | Drain bias and current readback | AN-10, AN-11 | Not started |
| [LAB-8](#lab-8-heater-drive-and-current-readback) | Heater drive and current readback | AN-14, AN-18 | Not started |
| [LAB-9](#lab-9-full-chain-vs-sr860) | Full chain vs SR860 | Scale factor and phase ([§2.9](#29-gain-distribution-headroom-and-demodulator-output)) | Not started |
 
### 8.3 Tests
 
#### LAB-1 Drain Node Waveforms (Oscilloscope)
 
**Purpose.** Measure the real drain DC level and AC swing of each transistor, and the active − blind difference, to confirm the common-mode level and the stage gain assumed in [§2.4](#24-transistor-operating-point). This can be done today on the existing bench setup.
 
**Setup.** Existing 3T bench setup (SR860 reference out on the gate, 330 kΩ drain resistors, heaters on the lab supply). CH1 on drain A, CH2 on drain B, both 10× probes, DC coupling for the DC level and AC coupling for the swing; math channel CH1 − CH2 for the differential. Use averaging (≥ 16) and a 20 MHz bandwidth limit. A 10× probe loads the drain with ≈ 10 MΩ ∥ ≈ 12 pF, which lowers the 518 Hz swing by ≈ 3 % (330 kΩ ∥ 10 MΩ); note it in the results.
 
**Expected.** Drain DC 50–250 mV; per-drain swing ≤ ≈ 200–400 mVpp for 5 mVpp excitation at room temperature (upper bound, r_0 ≫ R_D), scaling with the excitation amplitude; differential much smaller than either drain.
 
| Run | Date | V_G DC | δV_GS (setting) | V_heater A / B | I_D A / B | V_D DC A / B | v_d A / B (mVpp) | v_A − v_B (mVpp) | Phase A vs B | Files | Notes |
|-----|---|---|---|---|---|---|---|---|---|---|---|
| | | | | | | | | | | | |
 
<!-- ![Drain A, drain B and A−B on the scope](lab/LAB-1/drain_waveforms.png) -->
 
#### LAB-2 Bench Lock-in Reference Levels (SR560 / SR860)
 
**Purpose.** Record the maximum X/Y/R on the existing bench chain at the planned operating points, to confirm the signal-level assumption of [§2.5](#25-expected-signal-level-from-bench-data) and the gain plan of [§2.9](#29-gain-distribution-headroom-and-demodulator-output).
 
**Expected.** X/Y ≤ ≈ 400 mVrms with SR560 gain 20 and 5 mVrms excitation, i.e. ≤ 20 mVrms differential at the drains.
 
| Run | Date | Excitation (SR860, Vrms) | V_G DC | V_heater A / B | SR560 gain / filter | SR860 τ / slope | X | Y | R | θ | Files | Notes |
|-----|---|---|---|---|---|---|---|---|---|---|---|---|
| | | | | | | | | | | | | |
 
#### LAB-3 Power Rails
 
**Purpose.** Verify the DC level, ripple and low-frequency noise of each rail ([§3.5](#35-design-calculations), [§6](#6-power-budget)).
 
**Setup.** Scope, 20 MHz bandwidth limit, probe ground spring at the output capacitor; AC coupling for ripple. Input current from the bench supply display. Check the spectrum around 518 Hz with the scope FFT (no PFM bursts expected: FPWM, DC-7).
 
| Rail | Expected DC | Measured DC | Expected ripple (pp) | Measured ripple (pp) | Load / input current | Files | Notes |
|---|---|---|---|---|---|---|---|
| V_positive (+7 V) | 7.02 V | | 8–11 mV @ 500 kHz | | | | |
| V_negative (−7 V) | −7.02 V | | ≈ 5–6 mV @ 500 kHz | | | | |
| 5V_analog | 5.00 V | | ≪ 1 mV | | | | |
| N5V_analog | −4.99 V | | ≪ 1 mV | | | | |
| 3V3_digital | 3.30 V | | ≪ 1 mV | | | | |
| VIN current @ 12 V | ≈ 0.17–0.19 A (worst case) | | — | — | | | |
 
#### LAB-4 Quadrature Oscillator
 
**Purpose.** Verify amplitude, frequency, distortion and quadrature of the oscillator ([§4.5](#45-quadrature-oscillator-design)).
 
**Setup.** CH1 on sin, CH2 on cos (10× probes); frequency from the scope counter (and the MCU capture, AN-7a); THD from the scope FFT or the SR860 harmonic measurement; quadrature from the X–Y (Lissajous) display or the scope phase measurement.
 
| Run | Date | Amplitude sin / cos (Vpp) | Frequency (Hz) | Frequency from MCU (Hz) | THD sin / cos (%) | Phase sin → cos (°) | Reference after divider (Vpp) | Start-up time (s) | Files | Notes |
|-----|---|---|---|---|---|---|---|---|---|---|
| Expected | — | 6.3 / 6.3 | 518–521 (±1 %) | same | ≤ 1 | 90 ± 1 | 2.0 | ≈ 0.4 | — | Simulation, [§4.5.7](#457-simulated-performance-ideal-op-amps-ngspice) |
| | | | | | | | | | | |
 
#### LAB-5 Band-Pass Response
 
**Purpose.** Verify the INA + band-pass + ×4 gain chain against the design ([§2.8](#28-band-pass-filter-design)).
 
**Setup.** Function generator, 10 mVpp differential (or single-ended into one INA input with the other grounded through 330 kΩ), swept 100 Hz–5 kHz; measure at the ×4 output with the SR860 (gain and phase) or the scope.
 
| Run | Date | Gain at 518 Hz (V/V) | Phase at 518 Hz (°) | f_L −3 dB (Hz) | f_H −3 dB (Hz) | Gain at 1036 Hz rel. | Gain at 50 Hz rel. | Files | Notes |
|-----|---|---|---|---|---|---|---|---|---|
| Expected | — | 40 | 0 ± 1.6 | 377 | 711 | −10 dB | −41 dB | — | |
| | | | | | | | | | |
 
#### LAB-6 Common-Mode Rejection
 
**Purpose.** Measure the system CMRR ([§2.7](#27-common-mode-rejection)).
 
**Setup.** Drive both drain nodes with the same 518 Hz signal through their 330 kΩ resistors (transistors removed or gates grounded), measure the AD630 input or X/Y; repeat with a differential signal of known amplitude for the reference gain.
 
| Run | Date | CM input (Vpp) | Output for CM | DM input (Vpp) | Output for DM | CMRR (dB) | Files | Notes |
|-----|---|---|---|---|---|---|---|---|
| Expected | — | | | | | ≈ 56 (≥ 48) | — | |
| | | | | | | | | |
 
#### LAB-7 Drain Bias and Current Readback
 
**Purpose.** Verify drain DAC setting resolution (AN-10) and the drain current readback (AN-11) against a DMM/SMU.
 
| Run | Date | Channel | DAC setting (V) | Measured V_supply (DMM) | Measured V_D (DMM) | I_D from DMM (µA) | I_D from board (µA) | Error | Files | Notes |
|-----|---|---|---|---|---|---|---|---|---|---|
| | | | | | | | | | | |
 
#### LAB-8 Heater Drive and Current Readback
 
**Purpose.** Verify heater voltage range (AN-14) and current readback accuracy (AN-18).
 
| Run | Date | Heater | DAC setting (V) | Measured V_heater (DMM) | I_heater from DMM (mA) | I_heater from board (mA) | Error (µA) | Files | Notes |
|-----|---|---|---|---|---|---|---|---|---|
| | | | | | | | ≤ 100 (spec) | | |
 
#### LAB-9 Full Chain vs SR860
 
**Purpose.** Compare the board X/Y with the SR860 on the same sensor and operating point, and confirm the scale factor of [§2.9](#29-gain-distribution-headroom-and-demodulator-output) (V_X,ADC ≈ 76.4·v̂_diff·cos θ).
 
| Run | Date | Operating point | SR860 X / Y (Vrms, drain-referred) | Board X / Y (V at ADC) | Board X / Y drain-referred | Ratio | Phase offset (°) | Files | Notes |
|-----|---|---|---|---|---|---|---|---|---|
| | | | | | | | | | |
 
---
 
## 9. Open Items
 
| # | Item | Impact |
|---|---|---|
| 1 | Measure the actual drain AC swing per drain and the maximum X/Y on the bench at the planned operating points ([§2.4](#24-transistor-operating-point), [§2.5](#25-expected-signal-level-from-bench-data); [LAB-1](#lab-1-drain-node-waveforms-oscilloscope), [LAB-2](#lab-2-bench-lock-in-reference-levels-sr560--sr860)) | Confirms CM level, gain distribution and headroom |
| 2 | Verify INA828 input common-mode / output swing at G = 10 on ±5 V with drain levels 0–0.5 V (TI INA CM-range calculator) | Front-end headroom |
| 3 | Confirm INA828 input capacitance, bias current and CMRR vs frequency from the datasheet ([§2.6](#26-front-end-differential-conversion-first)) | CMRR, drain DC offset |
| 4 | Measure oscillator amplitude, frequency and THD on the first board; trim R1/R2 if the centre frequency needs tightening ([§4.5](#45-quadrature-oscillator-design); [LAB-4](#lab-4-quadrature-oscillator)) | Excitation accuracy |
| 5 | Second-source check for parts with 0 Mouser stock (OPA2192IDR, INA828IDR, STM32G474RET6) and the low-stock ADP7118-5.0 | Procurement |
 
---
 
## 10. References
 
Local copies are kept in the repository under `docs/`; the files will be added later. Paths below are where each document is expected.
 
### 10.1 Application Notes & White Papers
 
| ID | Document | Local file | Online |
|----|---|---|---|
| A1 | *Working With Inverting Buck-Boost Converters*, TI Application Note SNVA866B | [`docs/app_notes/snva866b.pdf`](docs/app_notes/snva866b.pdf) | [ti.com](https://www.ti.com/lit/an/snva866b/snva866b.pdf) |
| A2 | R. Mancini, *Design of op amp sine wave oscillators*, TI Analog Applications Journal SLYT164, Aug. 2000 | [`docs/app_notes/slyt164.pdf`](docs/app_notes/slyt164.pdf) | [ti.com](https://www.ti.com/lit/an/slyt164/slyt164.pdf) |
 
### 10.2 Component Datasheets
 
| ID | Component | Function on board | Local file | Online |
|----|---|---|---|---|
| D1 | LMR51430 (TI) | +7 V buck, −7 V IBB | [`docs/datasheets/lmr51430.pdf`](docs/datasheets/lmr51430.pdf) | [datasheet](https://www.ti.com/lit/ds/symlink/lmr51430.pdf) |
| D2 | ADP7118 (ADI) | +5 V / +3.3 V LDOs | [`docs/datasheets/adp7118.pdf`](docs/datasheets/adp7118.pdf) | [product page](https://www.analog.com/en/products/adp7118.html) |
| D3 | LT3094 (ADI) | −5 V LDO | [`docs/datasheets/lt3094.pdf`](docs/datasheets/lt3094.pdf) | [product page](https://www.analog.com/en/products/lt3094.html) |
| D4 | AD630 (ADI) | Balanced demodulator | [`docs/datasheets/ad630.pdf`](docs/datasheets/ad630.pdf) | [datasheet](https://www.analog.com/media/en/technical-documentation/data-sheets/ad630.pdf) |
| D5 | OPA2192 (TI) | General-purpose op amp | [`docs/datasheets/opa2192.pdf`](docs/datasheets/opa2192.pdf) | [product page](https://www.ti.com/product/OPA2192) |
| D6 | INA828 (TI) | Instrumentation amplifier | [`docs/datasheets/ina828.pdf`](docs/datasheets/ina828.pdf) | [product page](https://www.ti.com/product/INA828) |
| D7 | TMUX6136 (TI) | Channel switch | [`docs/datasheets/tmux6136.pdf`](docs/datasheets/tmux6136.pdf) | [product page](https://www.ti.com/product/TMUX6136) |
| D8 | DAC80508 (TI) | Gate / heater / drain DACs | [`docs/datasheets/dac80508.pdf`](docs/datasheets/dac80508.pdf) | [product page](https://www.ti.com/product/DAC80508) |
| D9 | ADS1220 (TI) | X/Y ADC | [`docs/datasheets/ads1220.pdf`](docs/datasheets/ads1220.pdf) | [product page](https://www.ti.com/product/ADS1220) |
| D10 | INA190 (TI) | Heater current sense | [`docs/datasheets/ina190.pdf`](docs/datasheets/ina190.pdf) | [product page](https://www.ti.com/product/INA190) |
| D11 | ISO7721 (TI) | UART isolator | [`docs/datasheets/iso7721.pdf`](docs/datasheets/iso7721.pdf) | [product page](https://www.ti.com/product/ISO7721) |
| D12 | TMP117 (TI) | Temperature sensor | [`docs/datasheets/tmp117.pdf`](docs/datasheets/tmp117.pdf) | [product page](https://www.ti.com/product/TMP117) |
| D13 | STM32G474RE (ST) | MCU | [`docs/datasheets/stm32g474re.pdf`](docs/datasheets/stm32g474re.pdf) | [product page](https://www.st.com/en/microcontrollers-microprocessors/stm32g474re.html) |
| D14 | SHT40 (Sensirion) | Humidity / temperature sensor | [`docs/datasheets/sht4x.pdf`](docs/datasheets/sht4x.pdf) | — |
| D15 | CP2102N (Silicon Labs) | USB-UART bridge | [`docs/datasheets/cp2102n.pdf`](docs/datasheets/cp2102n.pdf) | — |
 
### 10.3 Instrument Manuals
 
| ID | Instrument | Local file | Online |
|----|---|---|---|
| M1 | SR860 lock-in amplifier (Stanford Research Systems) | [`docs/manuals/sr860m.pdf`](docs/manuals/sr860m.pdf) | [manual](https://www.thinksrs.com/downloads/pdfs/manuals/SR860m.pdf) |
| M2 | SR560 low-noise preamplifier (Stanford Research Systems) | [`docs/manuals/sr560m.pdf`](docs/manuals/sr560m.pdf) | [manual](https://www.thinksrs.com/downloads/pdfs/manuals/SR560m.pdf) |

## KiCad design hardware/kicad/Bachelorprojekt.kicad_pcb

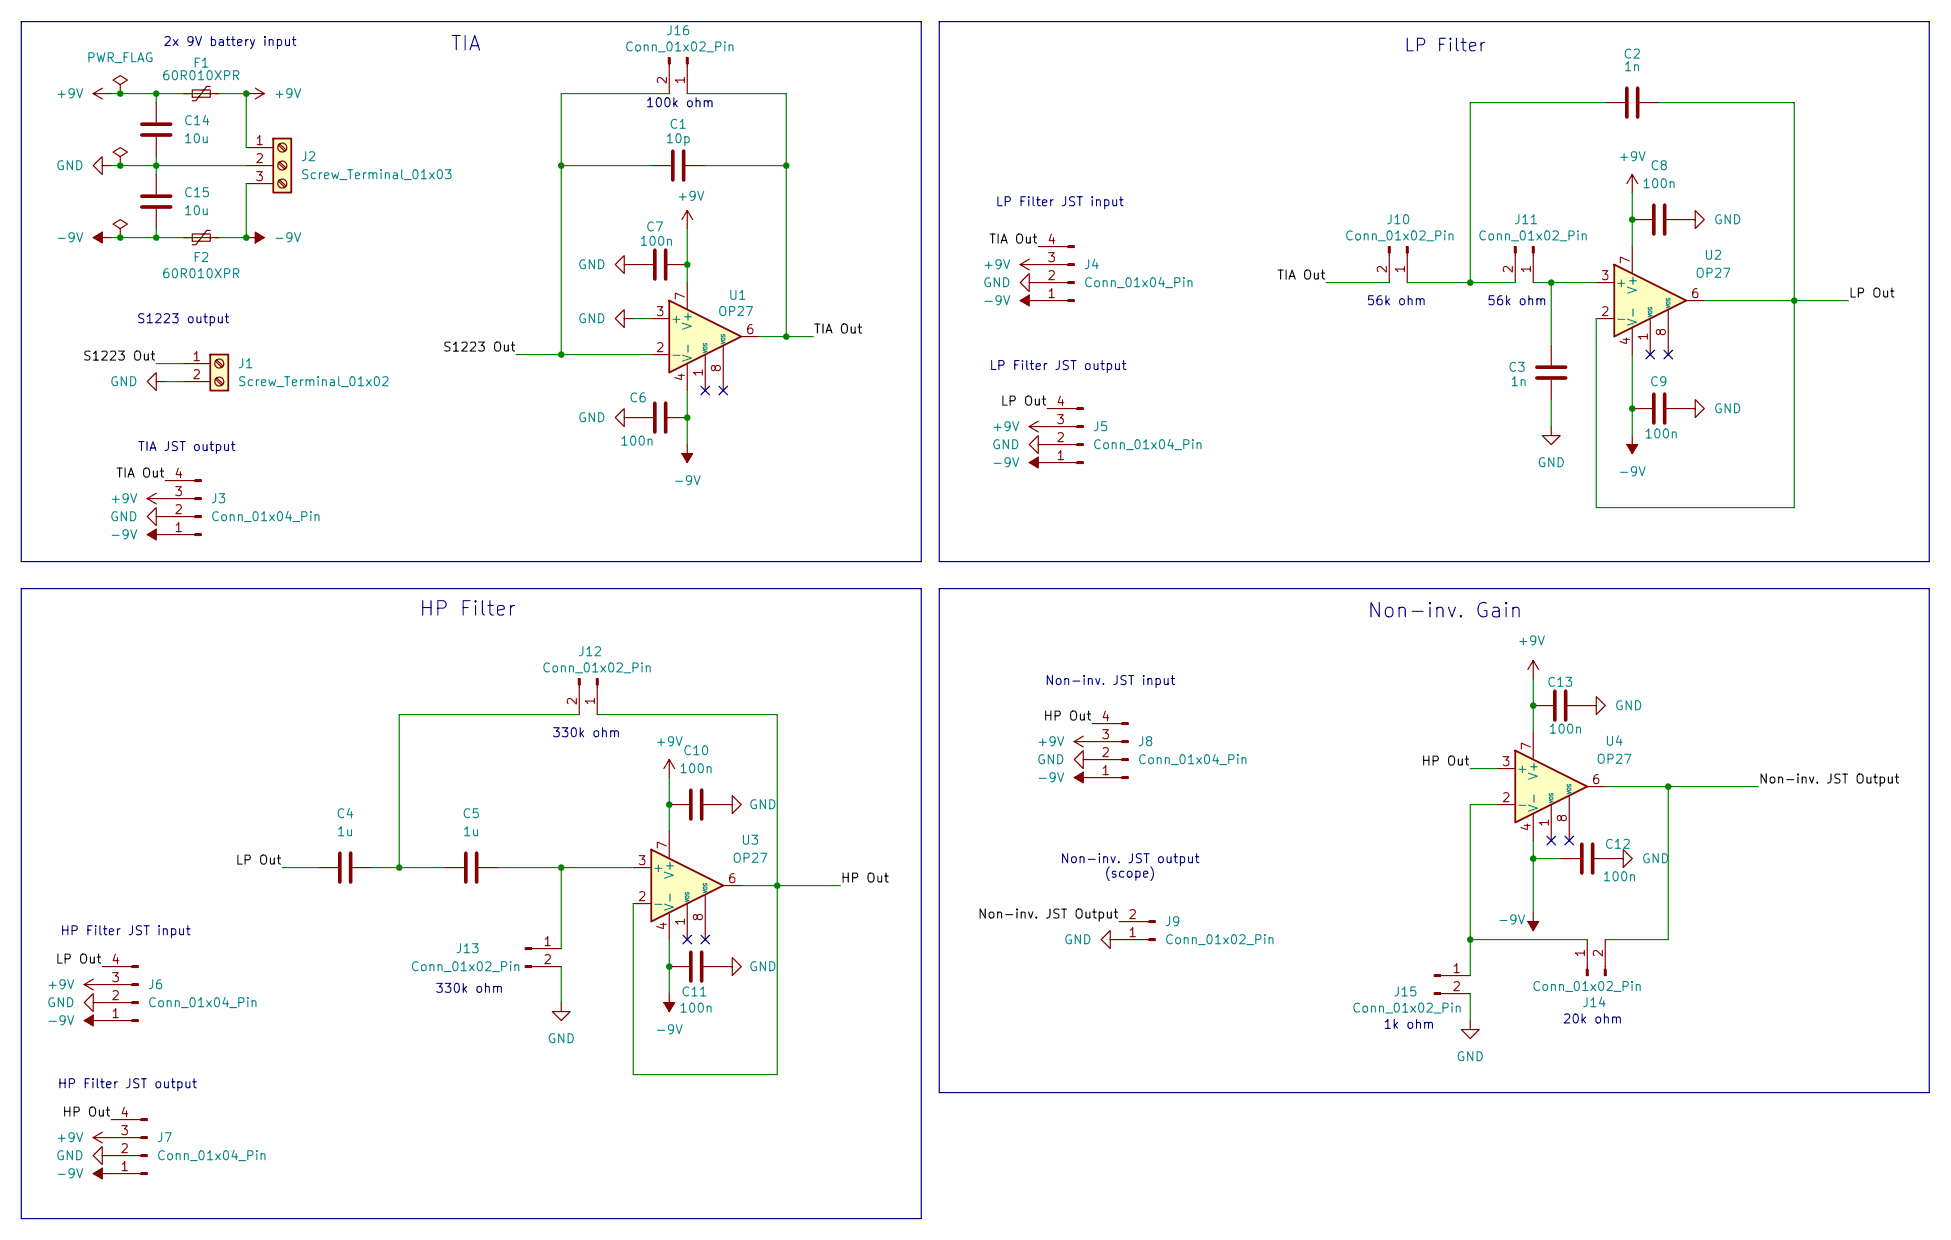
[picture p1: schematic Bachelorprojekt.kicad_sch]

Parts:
C1: 10p; C_Disc_D5.0mm_W2.5mm_P2.50mm
C2, C3: 1n; C_Rect_L7.0mm_W3.5mm_P5.00mm
C4, C5: 1u; C_Rect_L7.2mm_W7.2mm_P5.00mm_FKS2_FKP2_MKS2_MKP2
C6, C7, C8, C9, C10, C11, C12, C13: 100n; C_Rect_L7.0mm_W3.5mm_P5.00mm
C14, C15: 10u; C_Rect_L7.0mm_W4.5mm_P5.00mm
F1, F2: 60R010XPR; Fuse_Bourns_MF-RG300
J1: Screw_Terminal_01x02; TerminalBlock_MaiXu_MX126-5.0-02P_1x02_P5.00mm
J2: Screw_Terminal_01x03; TerminalBlock_MaiXu_MX126-5.0-03P_1x03_P5.00mm
J3, J4, J5, J6, J7, J8: Conn_01x04_Pin; JST_XH_B4B-XH-A_1x04_P2.50mm_Vertical
J9: Conn_01x02_Pin; JST_XH_B2B-XH-A_1x02_P2.50mm_Vertical
J10, J11, J12, J13, J14, J15, J16: Conn_01x02_Pin; PinSocket_1x02_P2.54mm_Vertical
U1, U2, U3, U4: OP27; DIP-8_W7.62mm_Socket

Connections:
+9V: C7.2, C8.1, C10.1, C13.1, C14.1, F1.1, F1.2, J2.1, J3.3, J4.3, J5.3, J6.3, J7.3, J8.3, U1.7 (V+), U2.7 (V+), U3.7 (V+), U4.7 (V+)
-9V: C6.2, C9.1, C11.1, C12.1, C15.2, F2.1, F2.2, J2.3, J3.1, J4.1, J5.1, J6.1, J7.1, J8.1, U1.4 (V-), U2.4 (V-), U3.4 (V-), U4.4 (V-)
/HP Out: J7.4, J8.4, J12.1, U3.2 (-), U3.6, U4.3 (+)
/LP Out: C2.2, C4.1, J5.4, J6.4, U2.2 (-), U2.6
/Non-inv. JST Output: J9.2, J14.2, U4.6
/S1223 Out: C1.1, J1.1, J16.2, U1.2 (-)
/TIA Out: C1.2, J3.4, J4.4, J10.2, J16.1, U1.6
GND: C3.1, C6.1, C7.1, C8.2, C9.2, C10.2, C11.2, C12.2, C13.2, C14.2, C15.1, J1.2, J2.2, J3.2, J4.2, J5.2, J6.2, J7.2, J8.2, J9.1, J13.2, J15.2, U1.3 (+)
unnamed: C2.1, J10.1, J11.2
unnamed: C3.2, J11.1, U2.3 (+)
unnamed: C4.2, C5.1, J12.2
unnamed: C5.2, J13.1, U3.3 (+)
unnamed: J14.1, J15.1, U4.2 (-)

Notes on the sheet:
1k ohm
20k ohm
TIA
HP Filter
S1223 output
Non-inv. JST output (scope)
LP Filter JST output
HP Filter JST output
Non-inv. Gain
56k ohm
HP Filter JST input
TIA JST output
Non-inv. JST input
2x 9V battery input
LP Filter
330k ohm
100k ohm
LP Filter JST input

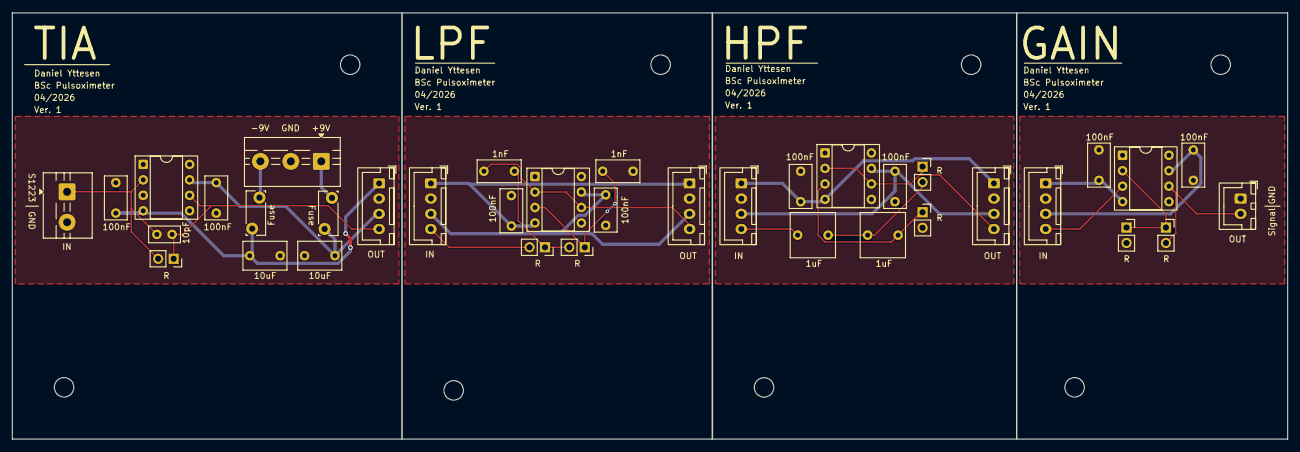
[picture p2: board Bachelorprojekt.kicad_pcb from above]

Board: 2 copper layers, 209.5 x 70.0 mm, 37 parts (0 on the bottom side), 13 nets.

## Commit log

2026-09-27 DC almost done
    [DC.kicad_sch]
2026-09-27 final before push to master
    [DC.kicad_sch]
2026-09-30 some minor changes to DC
    [DC.kicad_sch]
